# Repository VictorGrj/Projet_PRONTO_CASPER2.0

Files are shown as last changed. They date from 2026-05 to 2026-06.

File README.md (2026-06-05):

# Casper 2.0 – Robot interactif compagnon

Projet PRONTO – IMT Atlantique (S6 2025–2026 – Campus de Brest)

---
## Présentation

La vidéo de présentation du projet est accessible ici : 
https://www.youtube.com/watch?v=T89Vj4Z8cow

---

## Description

Casper 2.0 est un robot compagnon interactif développé dans le cadre du projet PRONTO.

L’objectif est d’améliorer une plateforme robotique existante afin de rendre les interactions plus naturelles et multimodales, en combinant :

- Interaction vocale en langage naturel
- Suivi visuel de l’utilisateur en temps réel
- Gestuelle synchronisée avec la parole
- Dialogue via intelligence artificielle (Google Gemini)

---

## Architecture du système

Le système repose sur une Raspberry Pi comme unité centrale, connectée à plusieurs modules :

- Caméra (vision)
- ReSpeaker Pi HAT (audio)
- API Gemini (IA)
- Synthèse vocale Piper
- Servomoteurs (PCA9685 via I2C)
- Interface graphique (Pygame)

---

## Architecture logicielle

Le projet est entièrement développé en Python avec une architecture multi-thread :

| Module | Rôle |
|---|---|
| `Main.py` | Orchestration globale (machine à états) |
| `AudioProcessing.py` | Capture audio + STT + IA + TTS |
| `CameraTracking.py` | Détection et suivi du visage |
| `Servo.py` | Contrôle des moteurs |
| `Screen.py` | Interface visuelle (expressions) |
| `Speak.py` | Lecture audio |

---

## Pipeline vocal

1. Capture audio via ReSpeaker
2. Transcription via Vosk
3. Traitement de la requête via Google Gemini API
4. Synthèse vocale via Piper TTS
5. Lecture audio synchronisée avec les mouvements

---

## Suivi visuel

- Détection de visage via OpenCV (Haar Cascade)
- Calcul du centre du visage
- Correction du servo moteur de la tête via PCA9685
- Arrêt automatique du tracking pendant la prise de parole

---

## Gestuelle

- Animation des bras synchronisée avec la parole
- Mouvements simplifiés pour réduire la charge CPU
- Optimisation pour Raspberry Pi (limitation des threads et PWM)

---

## Équipe projet

Projet réalisé par une équipe de 5 étudiants :

| Nom |
|-----|
| Greillier Matthieu |
| Lunven Nathan |
| Miannay Benjamin |
| Seillé Gautier |
| Garajeu Victor |

---

## Installation

```bash
git clone https://github.com/VictorGrj/Projet_PRONTO_CASPER2.0.git
cd Projet_PRONTO_CASPER2.0
pip install -r requirements.txt

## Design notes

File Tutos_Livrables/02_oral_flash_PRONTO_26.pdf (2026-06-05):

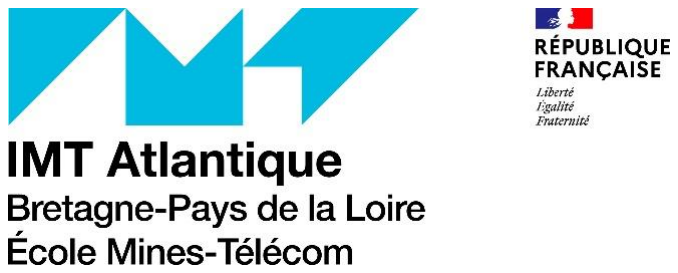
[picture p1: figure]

## PRONTO : Oral Flash Équipe n°2 : Casper 2.0

Garajeu Victor - Greillier Matthieu - Lunven Nathan -

Miannay Benjamin - Seillé Gautier

Encadré par : Lohr Christophe,

Kerdreux Jerôme, Abiven Bernard

## CONTEXTUALISATION

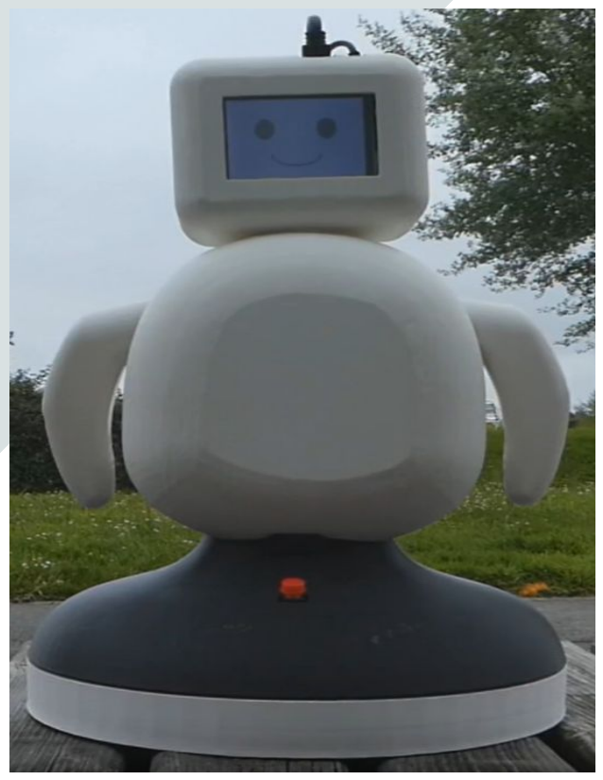
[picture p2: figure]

Casper
PRONTO 2024-2025

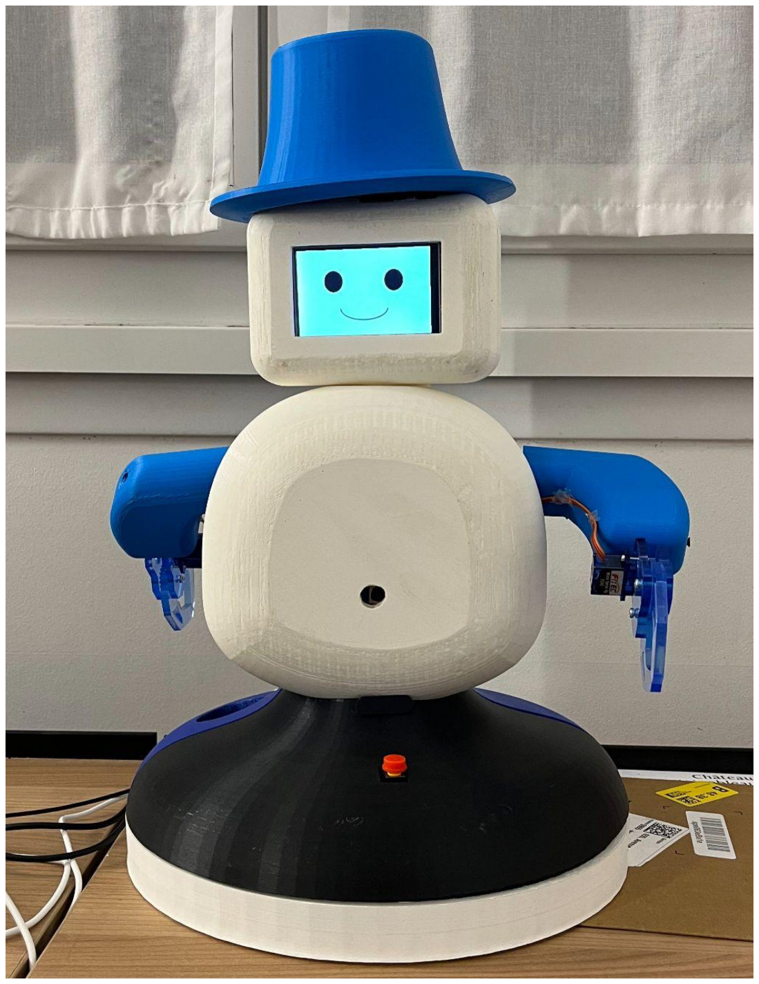
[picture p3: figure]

Casper 2.0
PRONTO 2025-2026

## OBJECTIF

### Comment rendre le robot Casper 2.0 plus naturel et autonome dans ses interactions avec un utilisateur?

## SOMMAIRE

### ❖ Fonctionnalités

### ❖ Méthodologie employée

### ❖ Résultats

### ❖ Perspectives d’amélioration

### ❖ Valorisation du Projet

### ❖ Démonstration

## FONCTIONNALITÉS

1) Interaction vocale
- Réponses générées par
IA
- Retrait du casque audio
- Dialogue vocal naturel
2) Suivi visuel
- Ajout d’une caméra
- Suivi de l’interlocuteur
3) Gestuelle
- Mouvements plus
fluides
- Mouvements en lien
avec la parole
- Nouveaux
servomoteurs
4) Intégration finale
- Robot complet
- Vidéo d’explication
- Tous les fichiers de
conception et de code

## MÉTHODOLOGIE

EMPLOYÉE | Intéraction Vocale

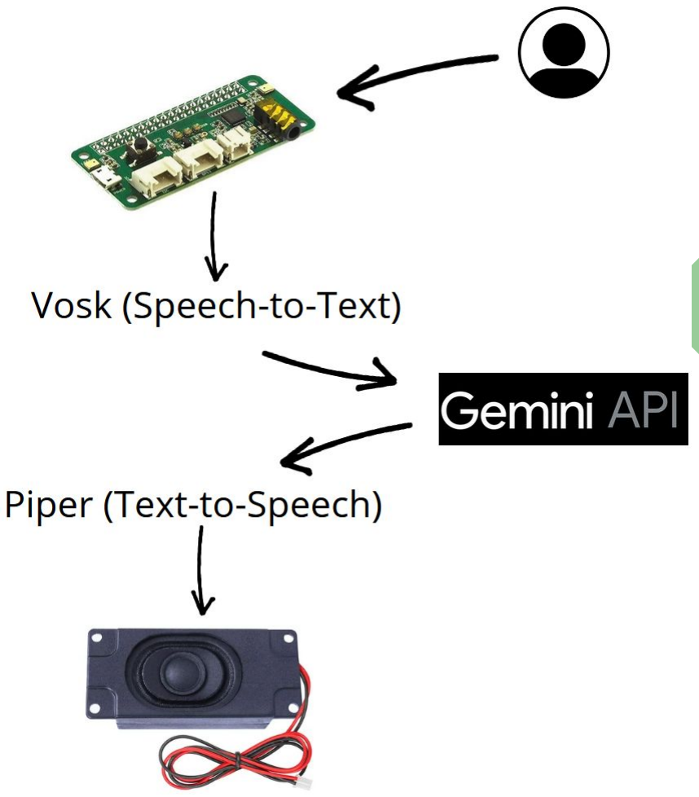
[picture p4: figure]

Objectifs :

- Échange plus fluide
- Génération de réponse par IA
- Ajout du module ReSpeaker

2 Pi HAT

- Test du code

## MÉTHODOLOGIE

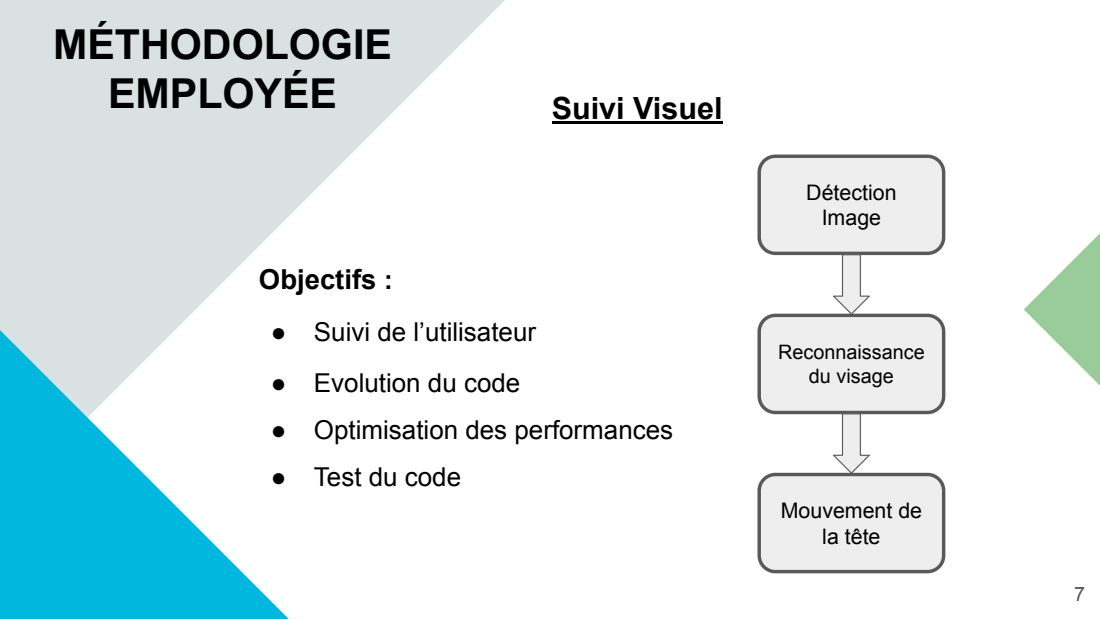
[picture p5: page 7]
EMPLOYÉE; Suivi Visuel; Objectifs :; Détection Image; Mouvement de la tête; Reconnaissance du visage

● Suivi de l’utilisateur

● Evolution du code
● Optimisation des performances

● Test du code

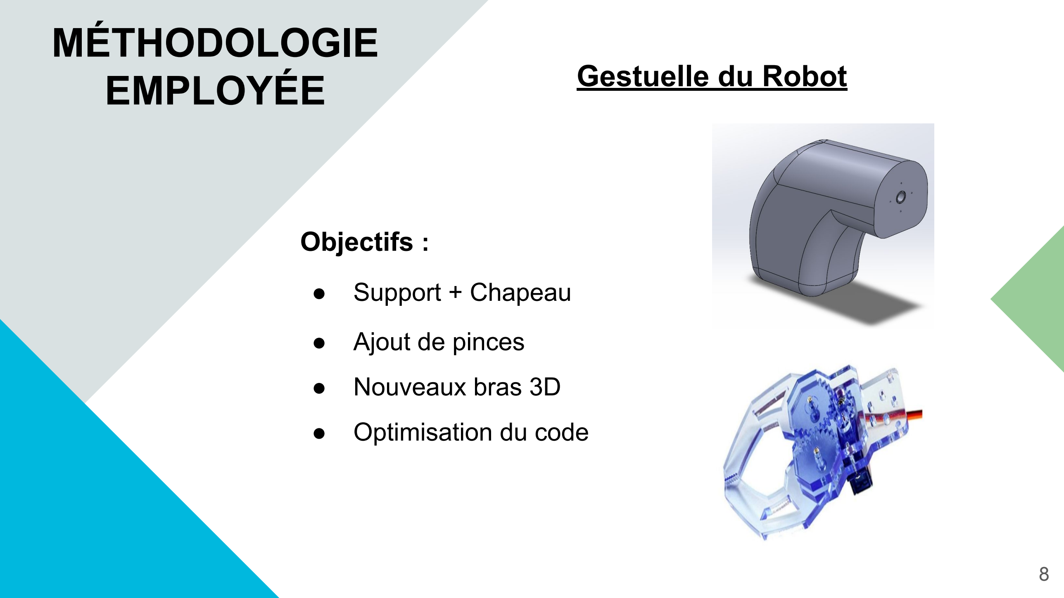
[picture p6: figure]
MÉTHODOLOGIE; EMPLOYÉE; Gestuelle du Robot; Objectifs :; ● Support + Chapeau; ● Ajout de pinces; ● Nouveaux bras 3D; ● Optimisation du code

## RÉSULTATS

1) Interaction vocale
- Réponse générée par IA
→ Réussi
- Dialogue vocal naturel
→ Fonctionnel (30s pour une réponse)
3) Gestuelle
- Mouvement en lien avec la parole → Réussi
- Nouveaux servomoteurs
→ Introduits
2) Suivi visuel
- Ajout d’une caméra
→ Réussi
- Suivi de l’interlocuteur → Réussi mais latence
4) Intégration finale
- Robot complet
→ Réussi
- Vidéo d’explication
→ Présente

Validation :

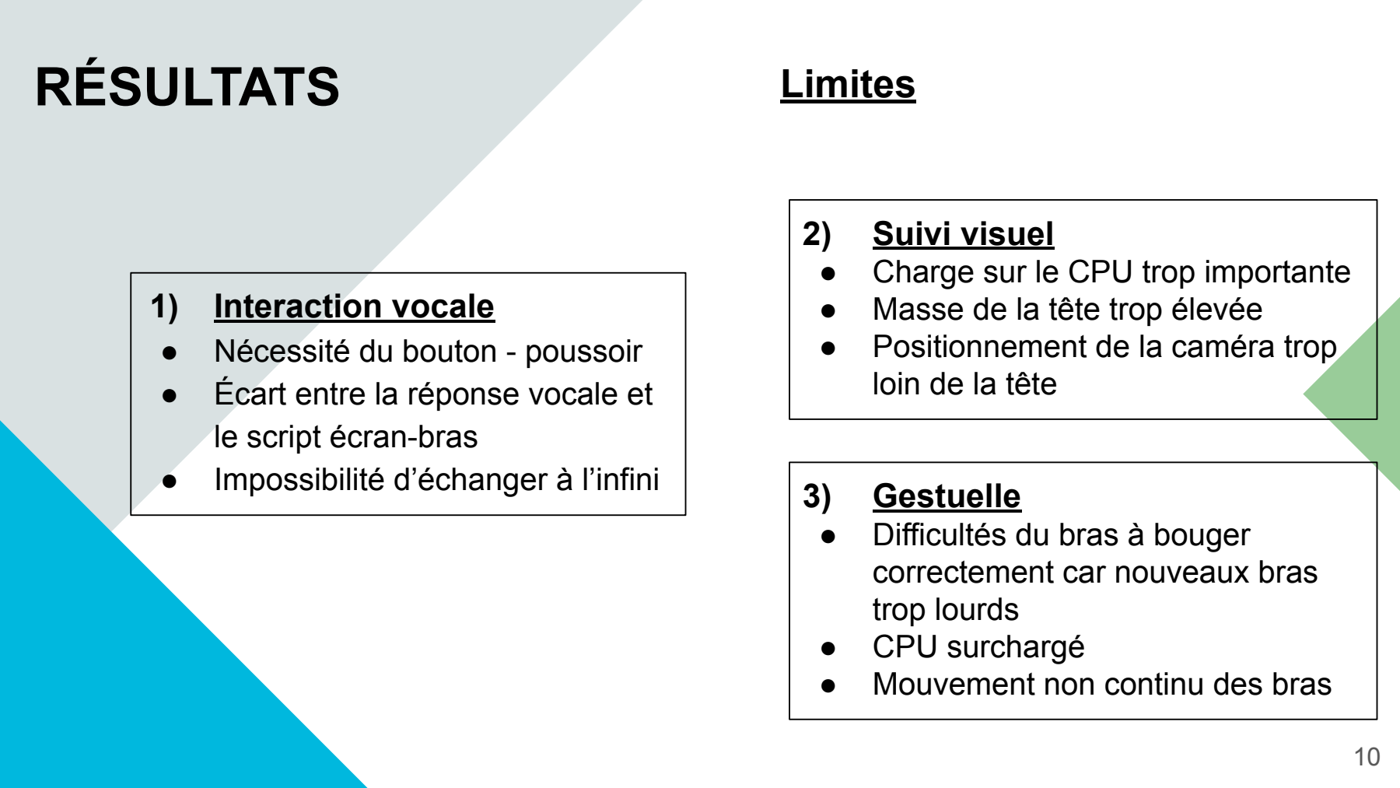
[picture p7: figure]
RÉSULTATS; Limites; 1) Interaction vocale; ● Nécessité du bouton - poussoir ● Écart entre la réponse vocale et; le script écran-bras ● Impossibilité d’échanger à l’infini; 2) Suivi visuel ● Charge sur le CPU trop importante ● Masse de la tête trop élevée ● Positionnement de la caméra trop loin de la tête; 3) Gestuelle ● Difficultés du bras à bouger correctement car nouveaux bras trop lourds ● CPU surchargé ● Mouvement non continu des bras

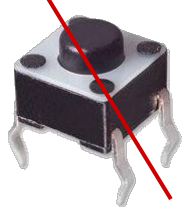
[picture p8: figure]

## PERSPECTIVES D'AMÉLIORATION

Objectifs:

- Remplacement du bouton par un mot-clé vocal
- Historique de conversation avec Gemini
- Localisation de la voix grâce aux deux microphones du ReSpeaker
- Gestuelle plus fluide

## VALORISATION DU PROJET

Méthode CAR

Contexte :

Modernisation d'un robot compagnon existant

Actions :

- Intégration de la vision à l’aide de la caméra
- Remplacement de wikipedia par gemini
- Conception et impression 3D de nouvelles pièces mécaniques

Résultats :

Réalisation d'un prototype capable de suivre un utilisateur et d'interagir vocalement de manière fluide

## Conclusion

Objectif atteint

- Interaction vocale avec intelligence artificielle
- Suivi visuel de l'utilisateur
- Gestuelle synchronisée avec la parole
- Intégration complète sur Raspberry Pi

Ce que nous retenons

- Développement d'un système robotique complet
- Intégration de plusieurs technologies (vision, audio, IA, mécanique)
- Travail d'équipe et gestion d'un projet d'ingénierie

# Avez-vous des questions ?

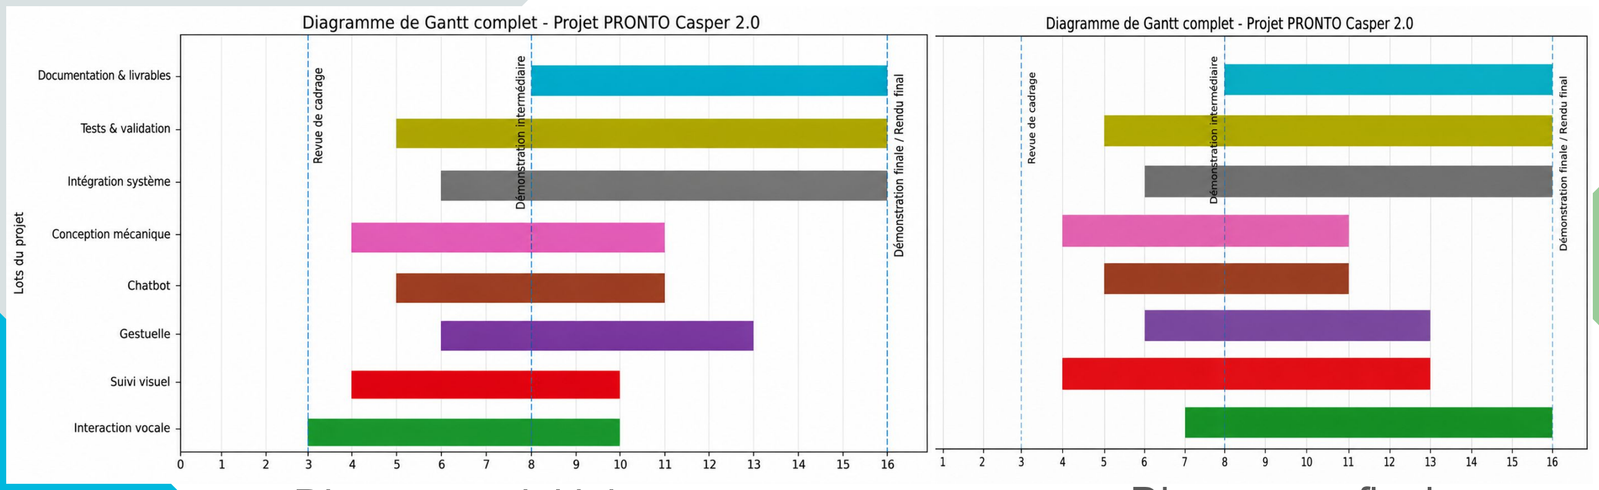
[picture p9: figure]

Diagramme initial | Diagramme final

Planification temporelle

## MÉTHODOLOGIE EMPLOYÉE

## VALORISATION DU PROJET

- Casper initial peu esthétique, avec des interactions limitées
- Modification des codes et ajout de périphérique afin de fluidifier les interactions
- Impression 3D afin de résoudre les problèmes d’esthétisme
- Obtention d’un robot plus esthétique pouvant avoir des interactions plus naturelles
- Gain en compétences
techniques (code et CAO)
- Première expérience
projet entreprise
- Gain en compétences de
gestion de projet de
groupes (prise de
décision collective,
gestion des conflits, ...)

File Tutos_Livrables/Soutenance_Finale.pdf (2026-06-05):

# PRONTO : Présentation finale Équipe n°2 : Casper 2.0

Garajeu Victor - Greillier Matthieu - Lunven Nathan -

Miannay Benjamin - Seillé Gautier

Encadré par : Lohr Christophe,

Kerdreux Jerôme, Abiven Bernard

## PROBLÉMATIQUE

ET

## OBJECTIF

## Comment implanter un chatbot dans le robot Casper, tout en y implémentant un suivi visuel et des mouvements en simultané ?

## SOMMAIRE

### ❖ Cahier des charges

### ❖ Conception du système

### ❖ Développement logiciel

### ❖ Intégration et validation

### ❖ Organisation et équipe

### ❖ Conclusion

## CAHIER DES CHARGES

1) Interaction vocale
- Ajout du Chatbot
- Retrait du casque
- Interaction plus fluide
2) Suivi visuel
- Ajout d’une caméra
- Suivi de l’interlocuteur
3) Gestuelle
- Mouvements plus
fluides
- Mouvements en lien
avec la parole
- Nouveaux
servomoteurs
4) Intégration finale
- Robot complet
- Vidéo d’explication
- Tous les fichiers de
conception et de code

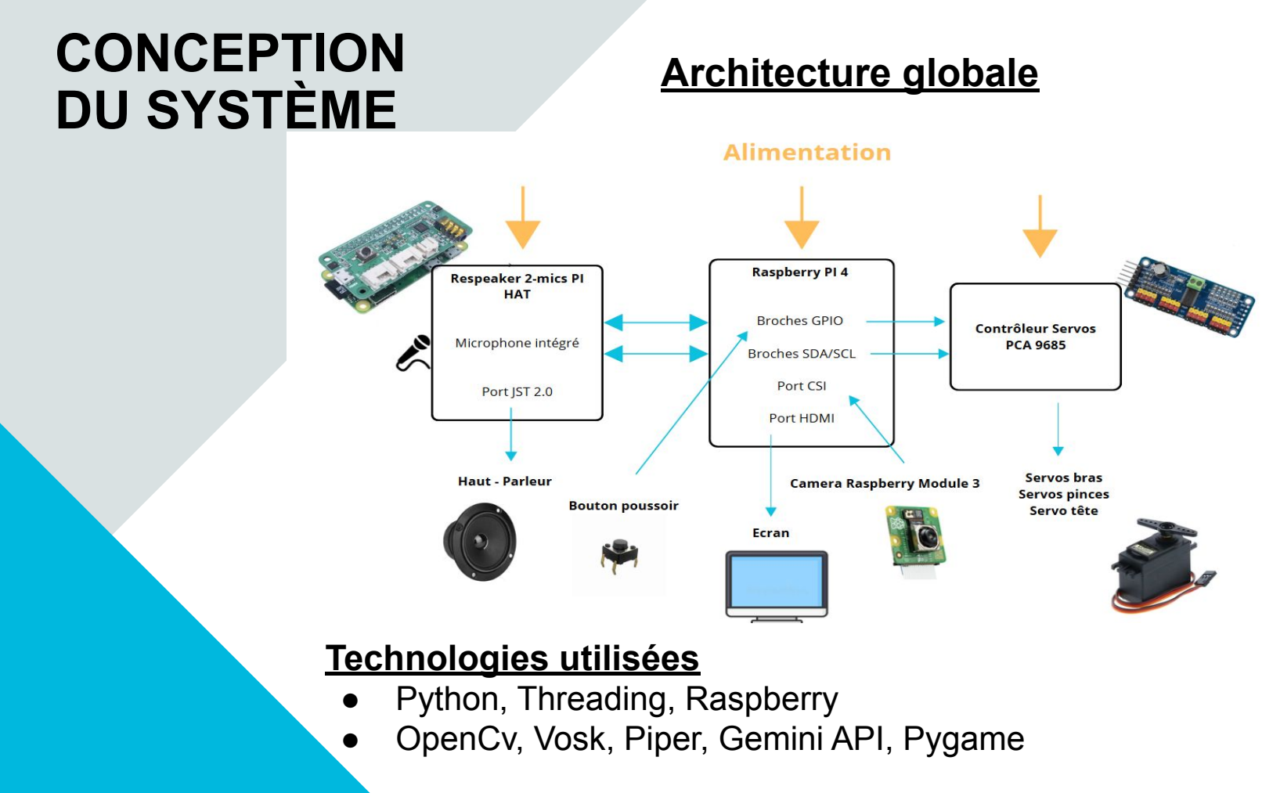
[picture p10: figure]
CONCEPTION DU SYSTÈME; Architecture globale; Technologies utilisées ● Python, Threading, Raspberry

- OpenCv, Vosk, Piper, Gemini API, Pygame

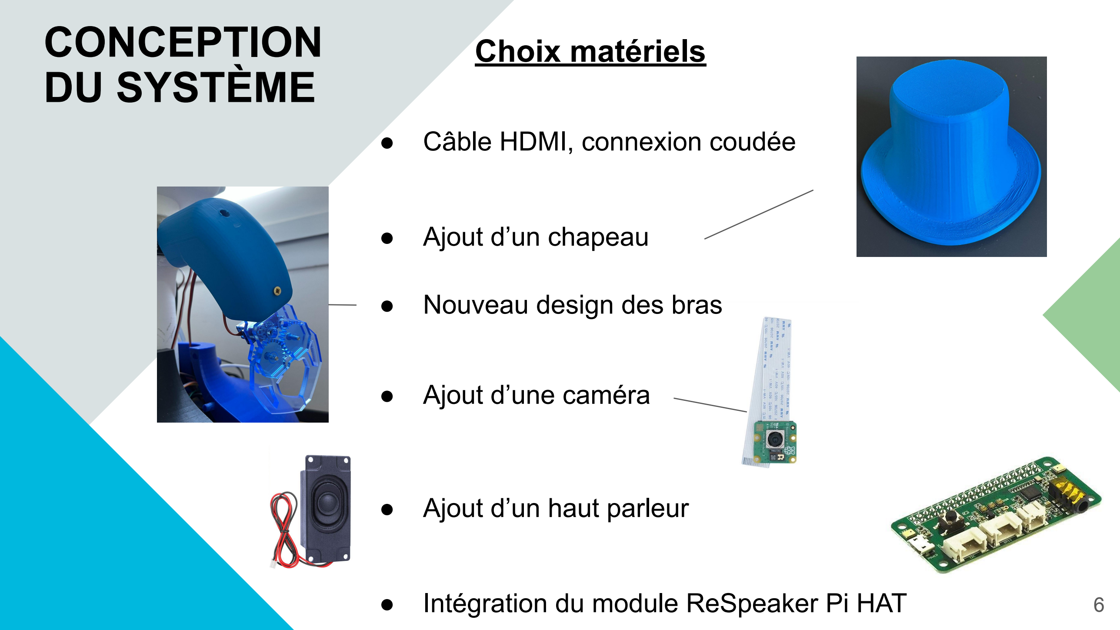
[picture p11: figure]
● Ajout d’un haut parleur; CONCEPTION DU SYSTÈME; Choix matériels; ● Câble HDMI, connexion coudée; ● Ajout d’un chapeau; ● Nouveau design des bras; ● Ajout d’une caméra

- Intégration du module ReSpeaker Pi HAT

### Interaction vocale

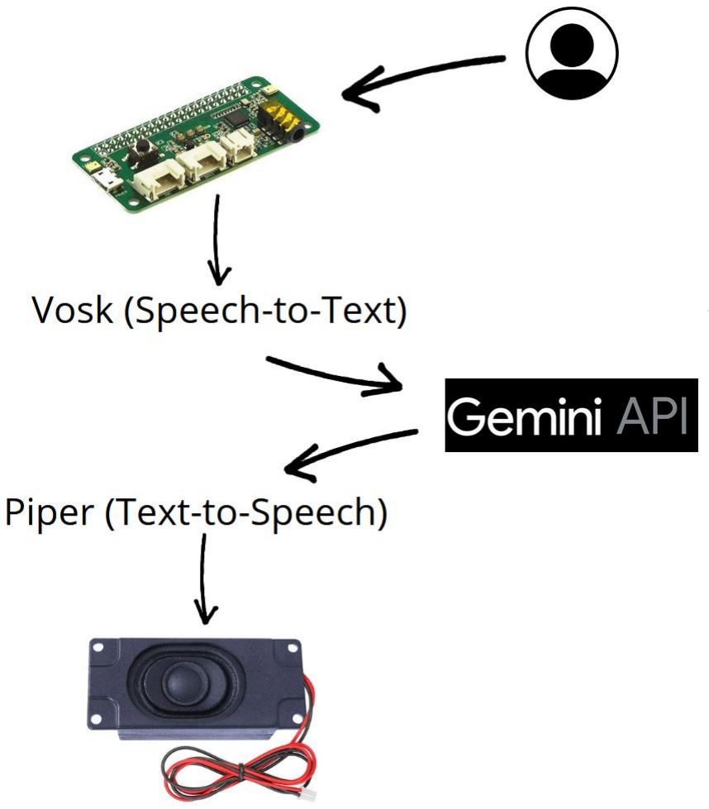
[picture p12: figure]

Objectifs :

- Échange plus fluide
- Utilisation d’une API IA (Gemini)
- Ajout du module ReSpeaker 2 Pi HAT
- Test du code

## DÉVELOPPEMENT DU SYSTÈME

## DÉVELOPPEMENT

DU SYSTÈME | Fonctionnement

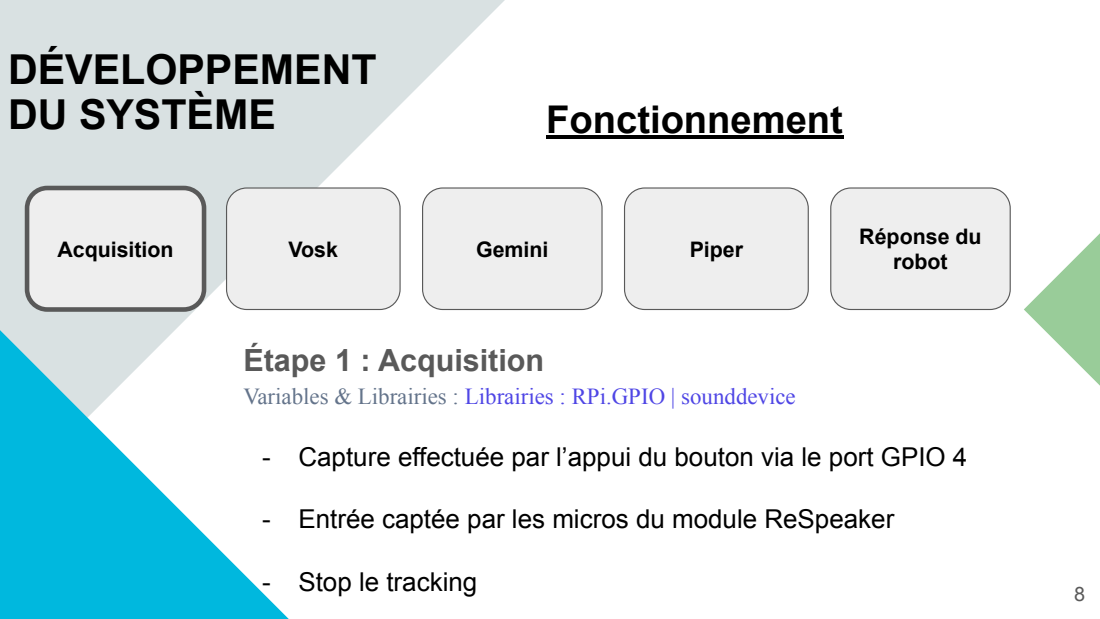
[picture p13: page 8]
Acquisition; Vosk; Gemini; Piper; Réponse du; robot; Étape 1 : Acquisition

Variables & Librairies : Librairies : RPi.GPIO | sounddevice

- Capture effectuée par l’appui du bouton via le port GPIO 4

- Entrée captée par les micros du module ReSpeaker

- Stop le tracking

## Fonctionnement

## DÉVELOPPEMENT

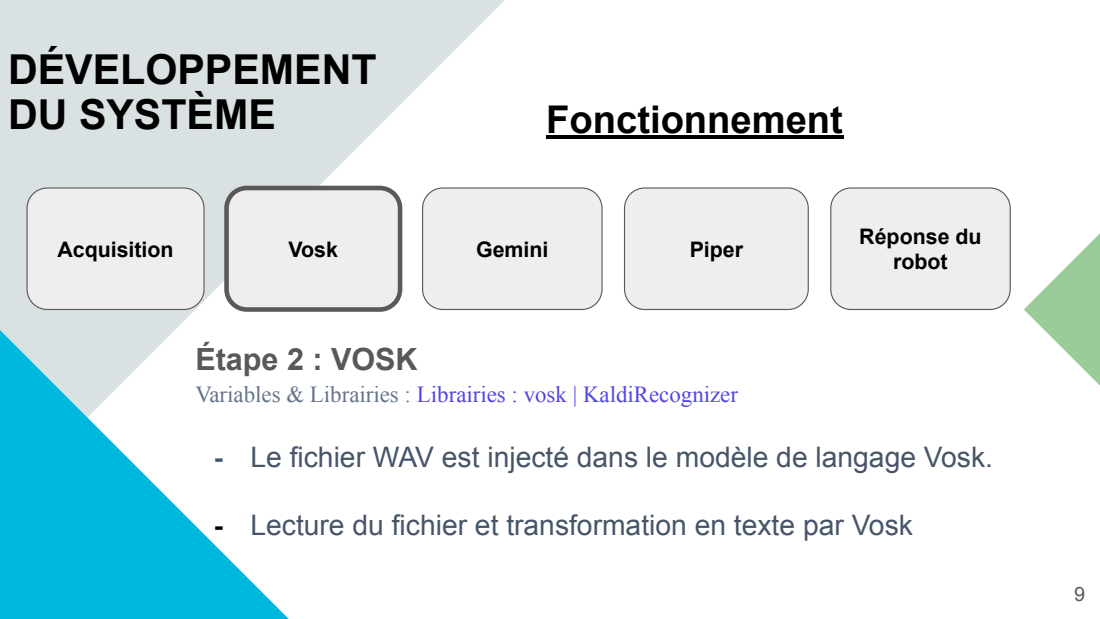
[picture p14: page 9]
Acquisition; Vosk; Gemini; Piper; Réponse du; robot; Étape 2 : VOSK; DU SYSTÈME

Variables & Librairies : Librairies : vosk | KaldiRecognizer

- Le fichier WAV est injecté dans le modèle de langage Vosk.

- Lecture du fichier et transformation en texte par Vosk

## Fonctionnement

## DÉVELOPPEMENT

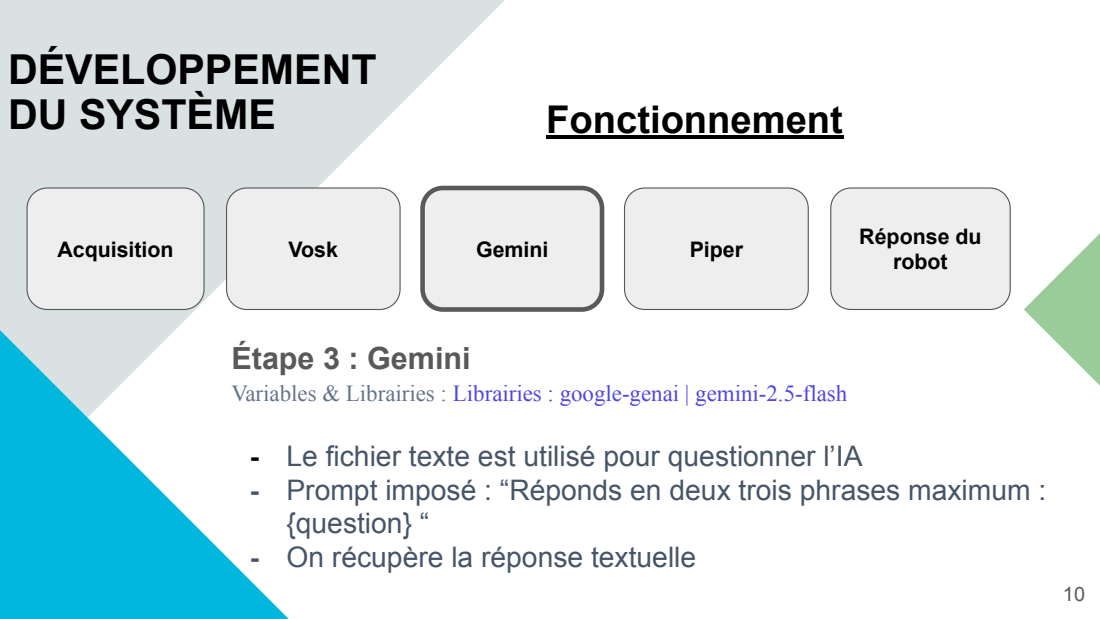
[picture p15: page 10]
Acquisition; Vosk; Gemini; Piper; Réponse du; robot; Étape 3 : Gemini; DU SYSTÈME

Variables & Librairies : Librairies : google-genai | gemini-2.5-flash

- Le fichier texte est utilisé pour questionner l’IA
- Prompt imposé : “Réponds en deux trois phrases maximum :
{question} “
- On récupère la réponse textuelle

## Fonctionnement

## DÉVELOPPEMENT

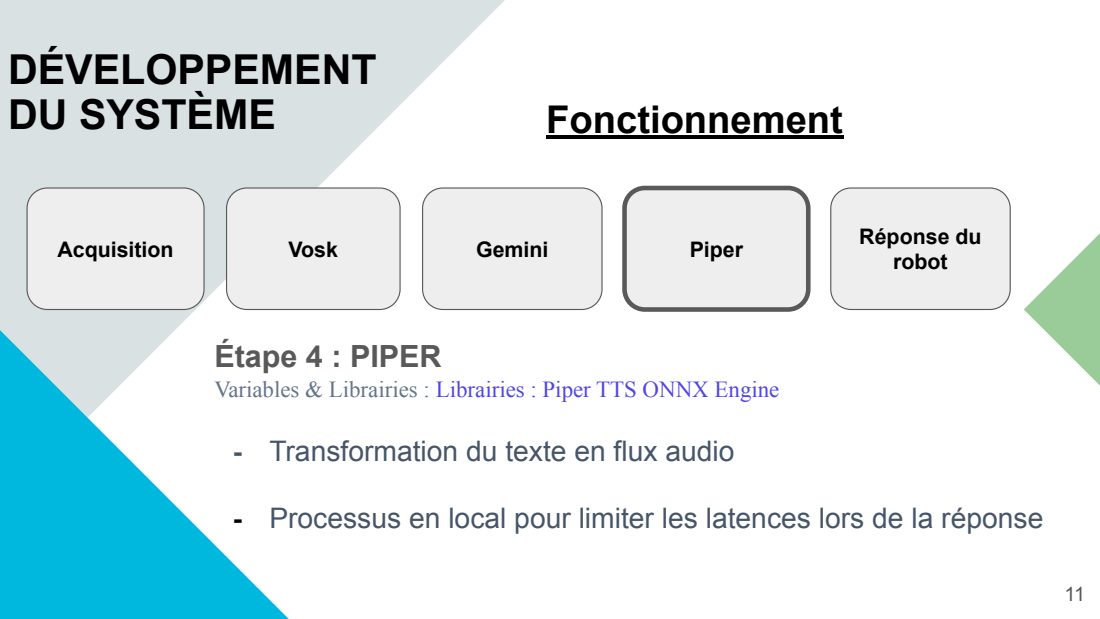
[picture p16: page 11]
Acquisition; Vosk; Gemini; Piper; Réponse du; robot; Étape 4 : PIPER; DU SYSTÈME

Variables & Librairies : Librairies : Piper TTS ONNX Engine

- Transformation du texte en flux audio

- Processus en local pour limiter les latences lors de la réponse

## Fonctionnement

## DÉVELOPPEMENT

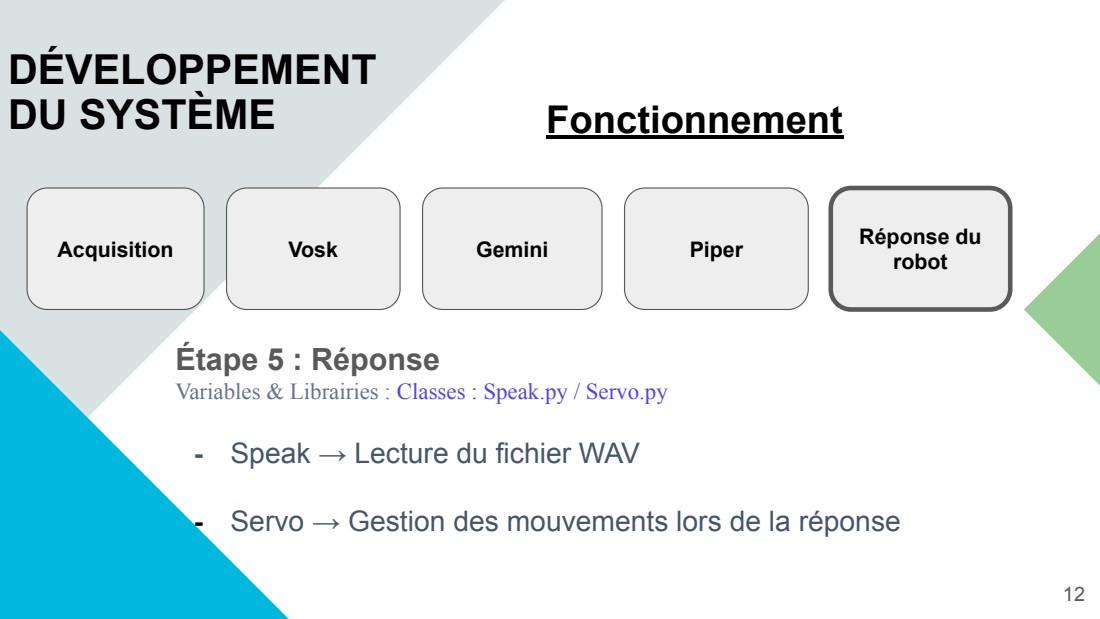
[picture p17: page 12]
Acquisition; Vosk; Gemini; Piper; Réponse du; robot; Étape 5 : Réponse; DU SYSTÈME

Variables & Librairies : Classes : Speak.py / Servo.py

- Speak → Lecture du fichier WAV

- Servo → Gestion des mouvements lors de la réponse

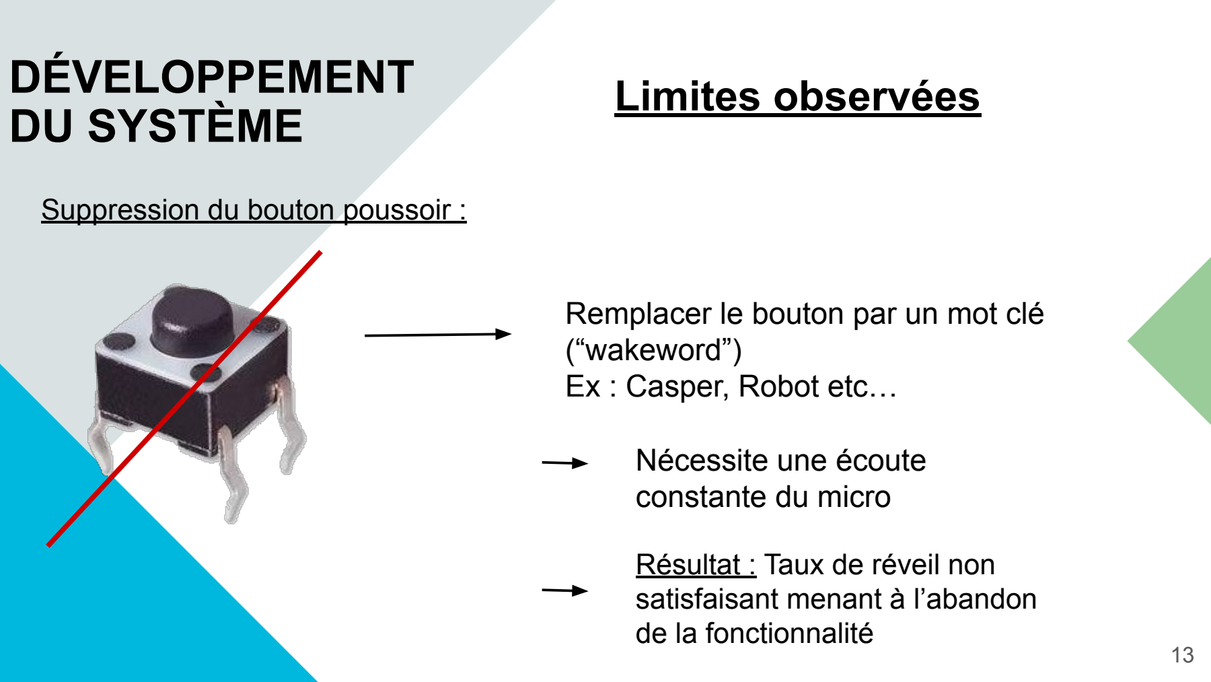
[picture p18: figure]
Limites observées; Suppression du bouton poussoir :; Remplacer le bouton par un mot clé (“wakeword”) Ex : Casper, Robot etc…; Nécessite une écoute constante du micro; Résultat : Taux de réveil non satisfaisant menant à l’abandon de la fonctionnalité; DÉVELOPPEMENT DU SYSTÈME

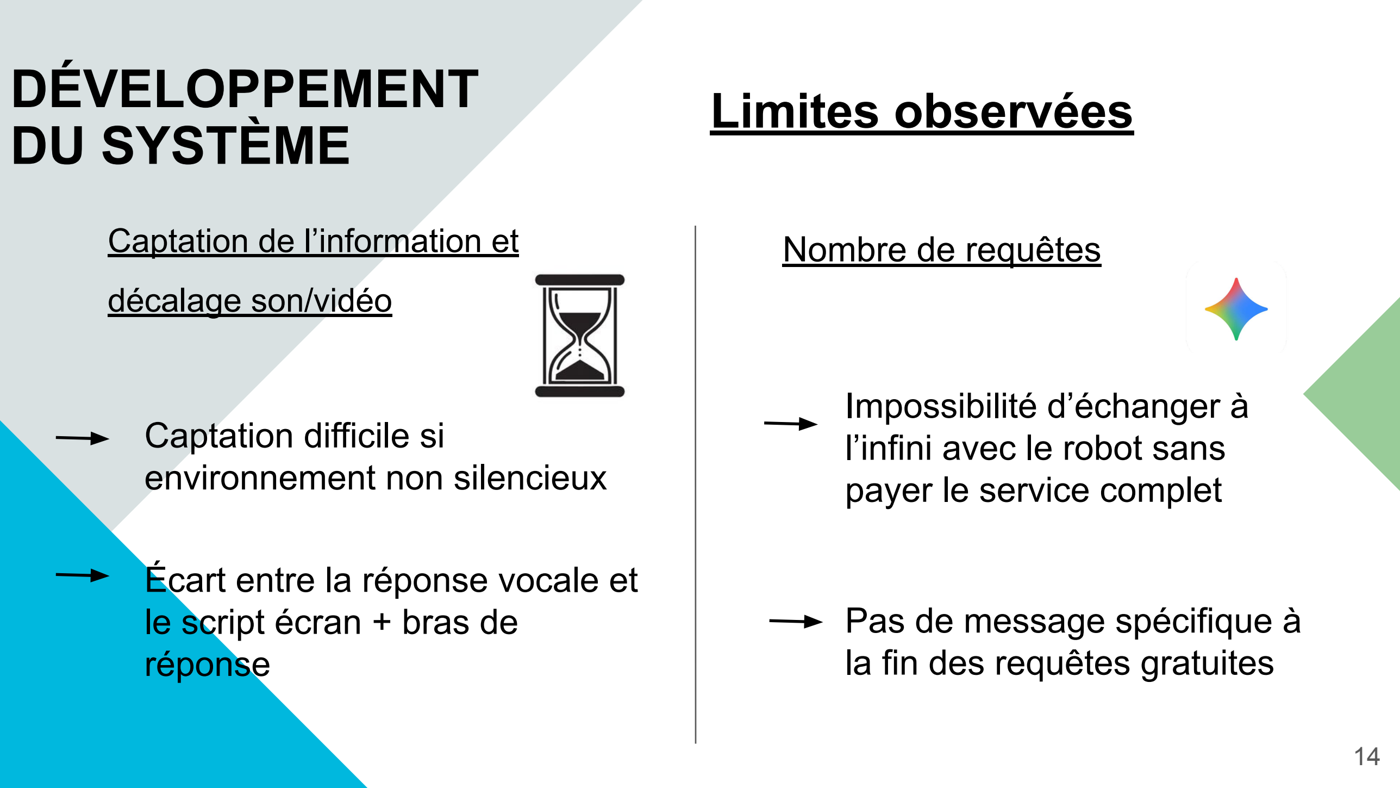
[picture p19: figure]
Limites observées; Captation de l’information et; décalage son/vidéo; Captation difficile si environnement non silencieux; Écart entre la réponse vocale et le script écran + bras de réponse; Nombre de requêtes; Impossibilité d’échanger à l’infini avec le robot sans payer le service complet; Pas de message spécifique à la fin des requêtes gratuites; DÉVELOPPEMENT DU SYSTÈME

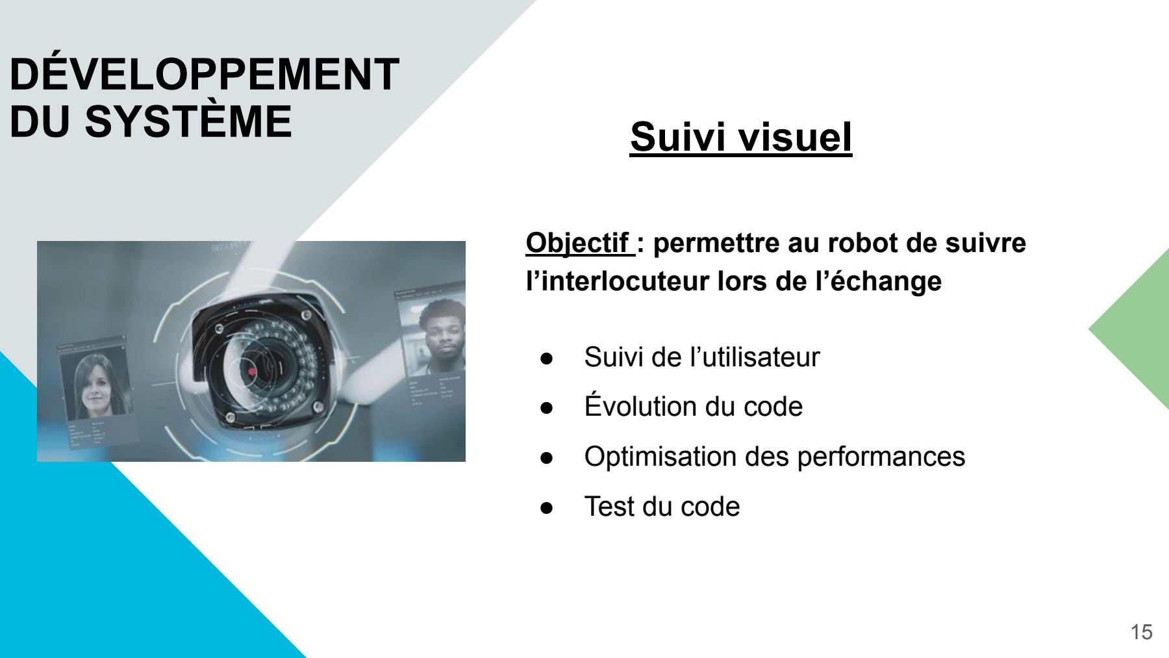
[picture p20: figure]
Suivi visuel; Objectif : permettre au robot de suivre l’interlocuteur lors de l’échange; ● Suivi de l’utilisateur; ● Évolution du code; ● Optimisation des performances; ● Test du code; DÉVELOPPEMENT DU SYSTÈME

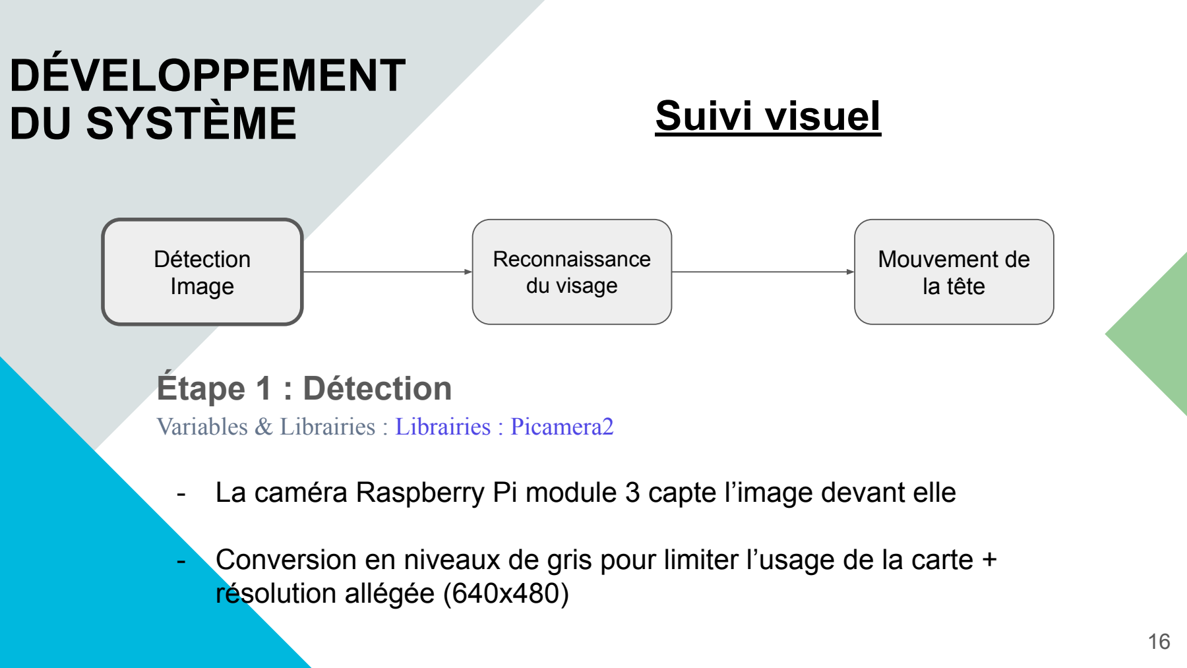
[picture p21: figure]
Suivi visuel; Détection Image; Reconnaissance du visage; Mouvement de la tête; Étape 1 : Détection; résolution allégée (640x480); DÉVELOPPEMENT DU SYSTÈME

Variables & Librairies : Librairies : Picamera2

- La caméra Raspberry Pi module 3 capte l’image devant elle
- Conversion en niveaux de gris pour limiter l’usage de la carte +

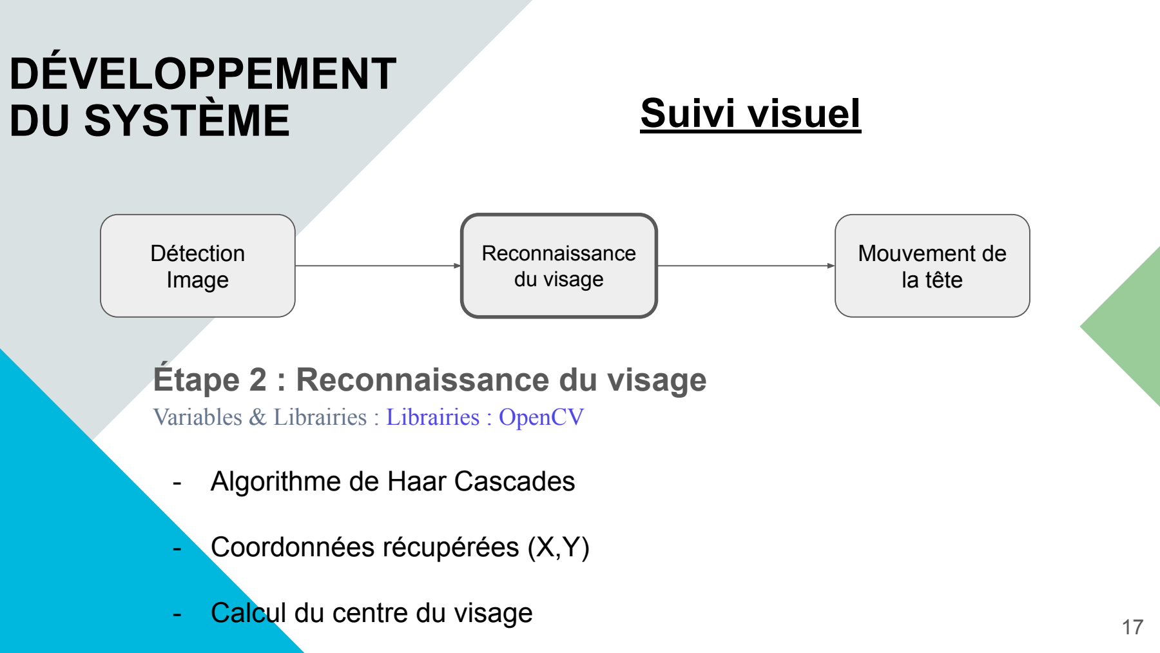
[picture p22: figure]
Suivi visuel; Détection Image; Reconnaissance du visage; Mouvement de la tête; Étape 2 : Reconnaissance du visage; - Algorithme de Haar Cascades; - Coordonnées récupérées (X,Y); - Calcul du centre du visage; DÉVELOPPEMENT DU SYSTÈME

Variables & Librairies : Librairies : OpenCV

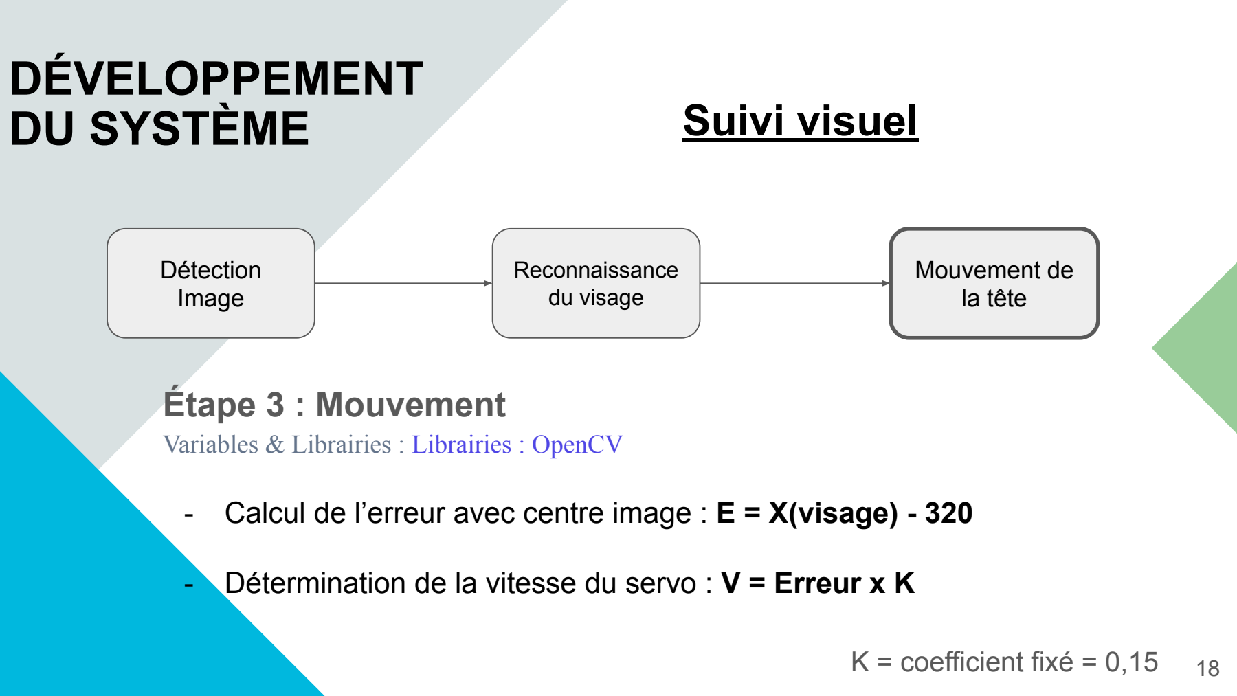
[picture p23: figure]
Suivi visuel; Détection Image; Reconnaissance du visage; Mouvement de la tête; Étape 3 : Mouvement; K = coefficient fixé = 0,15; DÉVELOPPEMENT DU SYSTÈME

Variables & Librairies : Librairies : OpenCV

- Calcul de l’erreur avec centre image : E = X(visage) - 320
- Détermination de la vitesse du servo : V = Erreur x K

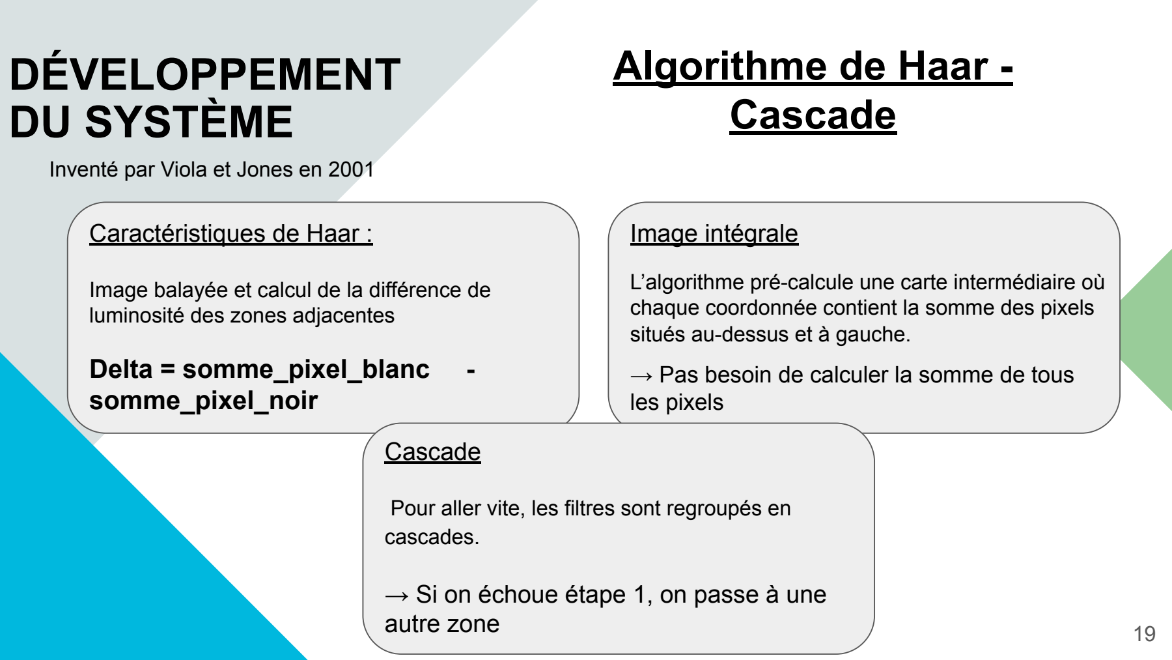
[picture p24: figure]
DÉVELOPPEMENT DU SYSTÈME; Algorithme de Haar - Cascade; Inventé par Viola et Jones en 2001; Caractéristiques de Haar :; luminosité des zones adjacentes; Delta = somme_pixel_blanc; somme_pixel_noir; Image intégrale; situés au-dessus et à gauche.; les pixels; Cascade; cascades.; → Si on échoue étape 1, on passe à une autre zone

Image balayée et calcul de la différence de

L’algorithme pré-calcule une carte intermédiaire où chaque coordonnée contient la somme des pixels

→ Pas besoin de calculer la somme de tous

Pour aller vite, les filtres sont regroupés en

## Limites de la feature

- Charge sur le CPU :

→ Malgré la coupure du script pendant la discussion, le tracking reste

vorace pour la Raspberry

- Longueur de la nappe :

→ Positionnement de la caméra loin de la tête

- Masse de la tête :

→ Mouvements saccadés lors du tracking

## DÉVELOPPEMENT DU SYSTÈME

## DU SYSTÈME


Diagramme initial | Diagramme final
DÉVELOPPEMENT | Planification temporelle

Gestuelle du robot; Objectif : Mouvements fluides adaptés; Optimisation du code :; Esthétisme :; → Méthode simple de mouvement lors de la réponse; → Limite l’usage du CPU; → Pinces en mouvement en même temps que les bras; DÉVELOPPEMENT DU SYSTÈME

### Limites

Ressources CPU :

100% des capacités du CPU sont utilisées pour la génération de la réponse

→ Mouvements des bras en
continu impossible sans surcharger la carte

Masse du nouveau bras

→ Masse des pinces à ajouter

→ Bras de levier plus important

## DÉVELOPPEMENT DU SYSTÈME

INTÉGRATION ET; VALIDATION; Ajouts sur la tête; → Exige de creuser la tête

Support Écran | Repose - Chapeau | Coude HDMI

## INTÉGRATION ET

## VALIDATION


### Ajouts sur les bras

Nouveaux bras | Pinces | Fixation des fils

Insertion dans
l'encoche du bras

## INTÉGRATION ET

## VALIDATION


Autres ajouts

Trou pour la caméra

ReSpeaker + extension GPIO

Servos
Bouton

Validation :

1) Interaction vocale
- Ajout Chatbot
→ Réussi
- Interaction plus fluide
→ Temps d’attente similaire
2) Suivi visuel
- Ajout d’une caméra
→ Réussi
- Suivi de l’interlocuteur → Réussi mais latence
3) Gestuelle
- Mouvement en lien avec la parole → Réussi
- Nouveaux servomoteurs
→ Introduits
4) Intégration finale
- Robot complet
→ Réussi
- Vidéo d’explication
→ Présente

## INTÉGRATION ET

## VALIDATION

ORGANISATION D’ÉQUIPE; Difficultés ● Travail cloisonné ● Communication limitée ● Retards; Solutions ● Points hebdomadaires ● Validation croisée ● Répartition plus souple; Résultats ● Meilleure cohésion ● Travail plus efficace; Climat au sein de l’équipe

## DÉMONSTRATION


## CONCLUSION


- Respect partiel du cahier des charges
- Réorganisation de l’équipe
- Amélioration du climat
- Efficacité augmentée

# Avez-vous des

# questions?

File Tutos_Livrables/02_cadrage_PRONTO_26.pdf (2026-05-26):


IMT Atlantique

Projet PRONTO – S6 2025-2026

Campus de Brest

Auteur 1 : Garajeu Victor

Auteur 2 : Greillier Matthieu

Auteur 3 : Lunven Nathan

Auteur 4 : Miannay Benjamin

Auteur 5 : Seillé Gautier

Encadré par : Lohr Christophe, Kerdreux Jerôme, Abiven Bernard

# PRONTO, S6 2025/2026

# Equipe n°2: Casper 2.0

# Document de cadrage

Version : 1.0

Date : 11 février 2026

## Table des matières

### INTRODUCTION :

L’Interaction Humain-Robot (Human-Robot Interaction, HRI) constitue un domaine de recherche majeur visant à améliorer l’acceptabilité, la compréhension et l’engagement des utilisateurs face aux systèmes robotiques.
Dans ce contexte, l’équipe de recherche RAMBO d’IMT Atlantique dispose d’une plate-forme robotique modulaire existante, nommée Wikibot, capable d’interagir vocalement avec un utilisateur en fournissant des définitions issues de Wikipédia.
Bien que fonctionnelle, cette première version présente plusieurs limitations, notamment une interaction essentiellement statique, l’absence de perception visuelle de l’interlocuteur et une interface audio peu adaptée à un usage naturel.
Le projet PRONTO « Robots compagnon : Casper 2.0 » s’inscrit dans la continuité de ce travail et vise à enrichir les capacités du robot afin de proposer des interactions plus naturelles, à la fois vocales et non verbales.

Le présent document constitue le document de cadrage du projet. Il présente l’état initial du projet à l’issue de la phase de cadrage, en abordant les aspects scientifiques, techniques et organisationnels, et servira de référence pour la préparation des revues de projet et d’équipe.

## Présentation du projet :

Le projet s’inscrit dans une démarche expérimentale en Interaction Humain-Robot (HRI), visant à améliorer la qualité et la naturalité des échanges entre un humain et un système robotique.

Finalité :
La finalité du projet est de contribuer à l’étude de l’acceptabilité des robots compagnons en proposant une plate-forme robotique capable de présence physique et d’interaction naturelle avec un utilisateur humain.

Mission :

La mission du système Casper 2.0 est d’étendre les capacités du robot existant en intégrant une interaction conversationnelle basée sur un chatbot en ligne. Un chatbot est un agent conversationnel logiciel capable de dialoguer automatiquement avec un utilisateur en langage naturel, généralement via une interface textuelle ou vocale, en s’appuyant sur des modèles de traitement automatique du langage. De plus le robot doit aussi intégrer un suivi visuel de l’interlocuteur et une gestuelle simple et fluide, afin de renforcer l’impression de présence et d’engagement durant l’échange.

Objectif :
Pour remplir cette mission, le projet vise notamment à :
- Permettre une interaction vocale compréhensible jusqu’à une distance de 3 mètres ;

- Assurer un suivi visuel de l’interlocuteur en temps quasi réel ;
- Synchroniser la gestuelle du robot avec la parole lors d’une interaction ;
- Livrer un prototype fonctionnel démontrable en environnement intérieur.

Contexte et problématique :
Le robot précédemment développé, Wikibot, se limitait à la restitution de définitions issues de Wikipédia et ne permettait pas une interaction conversationnelle riche. De plus, l’absence de perception visuelle et l’utilisation d’une interface audio contraignante limitent fortement la naturalité des échanges.
La problématique du projet consiste donc à concevoir une évolution du robot existant permettant une interaction plus naturelle, tout en respectant les contraintes de modularité, de calcul embarqué et d’environnement d’utilisation propres à la plate-forme existante.

## Cahiers des charges fonctionnel :

Le cahier des charges fonctionnel du projet Casper 2.0 définit les fonctions principales et contraintes nécessaires à la réalisation d’un robot compagnon capable d’interaction naturelle avec un utilisateur. Les fonctions principales concernent :

- L’interaction vocale avec l’utilisateur (captation et restitution du son)
- L’interfaçage avec une solution de chatbot en ligne
- Le suivi visuel de l’interlocuteur par mouvement de la tête
- L’animation gestuelle simple du robot lors des échanges

Les contraintes identifiées portent notamment sur :

- L’alimentation électrique du système
- L’intégration matérielle des composants (caméra, audio)
- La modularité et la maintenabilité du robot

La validation du besoin reposera sur des démonstrations expérimentales du prototype en conditions d’usage représentatives.

## Plan de Travail :

Etapes :
Le projet Casper 2.0 sera mené en effectuant des tâches en parallèles, combinant le développement logiciel, l’intégration matérielle et la conception mécanique.

Les étapes majeures du projet sont les suivantes :
- Prise en main du robot existant (Wikibot) et analyse de l’architecture matérielle et logicielle
- Etude et intégration d’un système de suivi visuel de l’interlocuteur à l’aide d’une caméra embarquée

- Développement et amélioration des algorithmes de mouvement afin d’obtenir une gestuelle fluide et naturelle
- Interfaçage avec une solution de chatbot en ligne pour permettre une interaction conversationnelle enrichie
- Conception et redesign de certaines pièces mécaniques afin d’intégrer les nouveaux composants tout en conservant la modularité du robot
- Intégration d’un système audio adapté (microphone et haut-parleur)
- Tests fonctionnels et démonstration du prototype final

Bibliographie :

Détail du projet précédent, base de notre compagnon à améliorer :

L. BONDUELLE, C. FELTIN, F. THOLLOT, A. MARION. « WIKIBOT - PROJET PRONTO »
HTTPS://GITHUB.COM/ASTRIDMARION/PROJET-PRONTO

Code permettant un suivi par reconnaissance faciale via une caméra :

W. COGLEY. « CAMERA-EYE FOLLOWER BOT » https://www.notion.so/nilheim-mechatronics/Camera-Eye-Follower-Bot-25524779b64d80969680f8a0c32fa70 (https://www.notion.so/nilheim-mechatronics/Camera-Eye-Follower-Bot-25524779b64d80969680f8a0c32fa70)

## Organisation de l’équipe :

Présentation :

L’équipe projet est composé de cinq étudiants aux compétences complémentaires en électronique, mécatronique, informatique, et rédaction technique.

- GARAJEU Victor, Compétences : Programmation, électronique, CAO ; Rôle technique principal : Responsable code et mécatronique
- GREILLIER Matthieu, Compétences : Electronique, mécatronique, bureautique ; Rôle technique principal : Responsable mécatronique
- SEILLE Gautier, Compétences : Electronique, mécatronique, CAO ; Rôle technique principale : Responsable CAO et conception mécanique
- LUNVEN Nathan, Compétences : Programmation, électronique ; Rôle technique principal : Responsable développement logiceil
- MIANNAY Benhamin, Compétences : Rédaction technique, structuration de documents ; Rôle technique principale : Responsable rédaction et livrable documentaires
•

Les rôles organisationnels (chef de projet, secrétaire, responsable bien-être) sont tournants afin de favoriser l’implication de tous les membres dans la gestion du projet. La répartition hebdomadaire de ces rôles est détaillée dans un tableau de suivi.

Périodes du 10/02 au 07/04

Rôle | 10/02-24/02 | 25/02-10/03 | 11/03-24/03 | 25/03-07/04
Manager | Gautier | Gautier | Benjamin | Benjamin
Médiateur | Victor | Matthieu | Nathan | Matthieu
Secrétaire général | Nathan | Victor | Gautier | Nathan

Périodes du 08/04 au 02/06

Rôle | 08/04-21/04 | 22/04-05/05 | 06/05-19/05 | 20/05-02/06
Manager | Victor | Victor | Matthieu | Matthieu
Médiateur | Nathan | Gautier | Gautier | Benjamin
Secrétaire général | Matthieu | Nathan | Victor | Gautier

Les moyens de communication que nous allons utiliser au cours de ce projet sont les suivants.

Communication interne :

- WhatsApp : communication quotidienne, organisation rapide et coordination de l’équipe
- Google Drive : partage et rédaction collaborative des documents
- GitLab : gestion du code source et versionnement des développements logiciels
- Overleaf : rédaction collaborative des rapports en LaTeX lors des phases de rendu
- Doc : rédaction collaborative des rapports sous forma Word lors des phases de rendu

Communication externe :

Messagerie Zimbra : échanges formels avec les encadrants du projet (hebdomadaire ou selon besoin).

WBS :

La structure de découpage du projet (WBS) est présentée ci-dessous. Elle décrit les lots principaux nécessaires à la réalisation du projet Casper 2.0, depuis la prise en main du robot existant jusqu’à la validation et la documentation du prototype final.


Les lots principaux présentés dans le WBS regroupent plusieurs sous-tâches techniques nécessaires à la réalisation complète du projet.
Le lot Analyse et prise en main comprend l’étude de l’architecture matérielle et logicielle du robot existant (Wikibot), la compréhension des flux de communication internes ainsi que l’évaluation des performances actuelles du système.
Le lot Développement logiciel intègre le développement des modules d’interaction vocale (capture et restitution audio), l’interfaçage avec une solution de chatbot en ligne, la mise en place d’un système de suivi visuel de l’interlocuteur via une caméra embarquée ainsi que l’amélioration des algorithmes de mouvement pour synchroniser la gestuelle avec la parole.
Le lot Conception mécanique comprend l’adaptation et le redesign de certaines pièces du robot afin d’intégrer les nouveaux composants (caméra, système audio), la modélisation CAO et la préparation des fichiers destinés à la fabrication.
Le lot Intégration et validation regroupe l’assemblage progressif des différents modules développés, la réalisation de tests fonctionnels intermédiaires, l’optimisation des performances et la validation expérimentale en conditions représentatives d’usage.
Enfin, le lot Documentation et livrables inclut la rédaction des documents scientifiques et techniques, la production du dossier de conception, du tutoriel Do-It-Yourself ainsi que la préparation de la démonstration finale et des supports de communication.

Planification temporelle du projet : Le projet Casper 2.0 est planifié sur la durée du semestre selon une organisation progressive et partiellement itérative. La planification repose sur les lots principaux identifiés dans le WBS.

Les premières semaines sont consacrées à la prise en main du robot existant (Wikibot) et à l’analyse de l’architecture matérielle et logicielle. Les développements liés à l’interaction vocale, au suivi visuel et à l’interfaçage avec un chatbot sont ensuite menés en parallèle.
La conception mécanique et l’intégration des nouveaux composants sont réalisées de manière itérative afin de s’adapter aux contraintes identifiées au cours du projet.
Les dernières semaines sont dédiées à l’intégration globale, aux tests fonctionnels, à la validation du prototype et à la production des livrables.

Le diagramme de Gantt présenté ci-dessous illustre cette planification ainsi que les principaux jalons du projet.


Tableau des livrables :

Les livrables du projet Casper 2.0 sont à la fois scientifiques, techniques et organisationnels. Ils jalonnent l’avancement du projet et permettent de valider les différentes étapes de conception, d’intégration et de démonstration du prototype.

Le tableau ci-dessous présente les principaux livrables du projet, leur nature, leur description et leur date de remise prévisionnelle. Les dates indiquées sont susceptibles d’évoluer en fonction des contraintes techniques rencontrées au cours du projet.

Livrable | Nom | Type | Description | Échéance
L1 | Document de cadrage du projet | Organisationnel | Présentation du contexte, des objectifs, du cahier des charges synthétique, de la planification, de l’organisation de l’équipe et de l’analyse initiale des risques | Semaine 3
L2 | Cahier des charges fonctionnel | Scientifique / Technique | Définition des fonctions principales et contraintes du robot Casper 2.0 ainsi que des critères de validation | Semaine 3
L3 | Codes sources du projet | Technique | Code du système embarqué, des modules d’interaction vocale, de suivi visuel et d’interfaçage chatbot | Semaine 16
L4 | Fichiers de conception mécanique | Technique | Modèles CAO et fichiers d’impression 3D des pièces modifiées ou ajoutées | Semaine 16
L5 | Prototype final fonctionnel | Technique | Robot Casper 2.0 intégrant l’ensemble des fonctionnalités validées | Semaine 16

L6 | Dossier de conception | Scientifique / Technique | Description argumentée des choix techniques matériels et logiciels, en lien avec l’état de l’art | Semaine 16
L7 | Tutoriel Do-It-Yourself | Scientifique / Technique | Guide expliquant les étapes de réalisation et de reproduction du projet | Semaine 16
L8 | Vidéo de démonstration | CommunicationCourte vidéo illustrant le fonctionnement et les capacités | du robot | Semaine 16

Analyse initiale des risques :

Cette analyse vise à identifier les principaux risques techniques, organisationnels et externes susceptibles d’impacter le bon déroulement du projet Casper 2.0. Pour chaque risque identifié, une estimation de la probabilité et de l’impact est proposée, ainsi que des actions de prévention ou de mitigation.

Cette analyse sera mise à jour tout au long du projet en fonction de l’avancement et des difficultés rencontrées.

ID | Risque identifié | Type | Probabilité | Impact | Actions préventives
R1 | Indisponibilité ou panne du robot existant | Technique / Externe | Faible | Élevé | Vérification rapide de l’état du robot, sauvegarde des fichiers existants
R2 | Indisponibilité ou retard de livraison de composants matériels (caméra, carte audio) | Externe | Moyenne | Moyen | Anticipation des commandes, choix de composants standards
R3 | Modification ou indisponibilité du service de chatbot en ligne | Externe | Faible à moyenne | Moyen | Prévoir une solution alternative, tester plusieurs API
R4 | Limitation des performances matérielles de la carte Raspberry Pi | Technique | Moyenne | Moyen | Tests progressifs, optimisation logicielle

R5 | Contraintes d’accès aux salles ou au matériel du Fablab | Organisationnel / Externe | Faible | Moyen | Planification anticipée des séances
R6 | Problèmes de compatibilité entre bibliothèques logicielles externes | Technique | Moyenne | Moyen | Choix de solutions éprouvées, tests unitaires

## Conclusion :

Ce document de cadrage a permis de définir le cadre général du projet PRONTO Casper 2.0, en précisant le contexte, les objectifs, le cahier des charges fonctionnel, l’organisation de l’équipe ainsi que la planification prévisionnelle du projet.
Les principaux risques techniques et organisationnels ont été identifiés afin d’anticiper les difficultés potentielles et de mettre en place des actions de prévention adaptées.
La prochaine étape correspond à la phase 2 – Production. Cette phase consistera à prendre en main le robot existant (Wikibot), à démarrer les développements logiciels et matériels, et à réaliser les premières intégrations des nouvelles fonctionnalités. Un suivi régulier de l’avancement sera assuré afin d’adapter les choix techniques et la planification en fonction des contraintes rencontrées.
La phase 2 débutera par une prise en main complète du robot existant et le lancement des premiers développements logiciels et intégrations matérielles.

## Annexe :

Contrat d’équipe :
Le contrat d’équipe présenté ci-dessous a été établi lors de l’atelier « Former son équipe ». Il définit les règles de fonctionnement interne, les engagements des membres, les modalités de communication ainsi que la gestion des conflits et des absences au sein de l’équipe projet.


Cahier des charges fonctionnel : Le cahier des charges fonctionnel détaillé, présenté dans le document principal, définit les fonctions principales et contraintes du robot Casper 2.0 ainsi que les critères de validation associés.



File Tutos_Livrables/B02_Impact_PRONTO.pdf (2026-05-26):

IMT Atlantique
Projet PRONTO – S6 2025-2026 Campus de Brest


# PRONTO, S6 2025/2026 Equipe n°2: Casper 2.0

# Document d’étude d’impact

Version : 1.0
Date : 25 mars 2026

Auteur 1 : Garajeu Victor
Auteur 2 : Greillier Matthieu Auteur 3 : Lunven Nathan
Auteur 4 : Miannay Benjamin
Auteur 5 : Seillé Gautier
Encadré par : Lohr Christophe, Kerdreux Jerôme, Abiven Bernard

## Descriptif général du projet :

Le projet s’inscrit dans une démarche expérimentale en Interaction Humain-Robot (HRI), visant à transformer un robot déjà existant (Wikibot ou Casper), en un robot compagnon plus poussé, capable d’interactions naturelles. Le robot initial, bien que fonctionnel, se limitait à une interaction statique et purement informative sans perception visuelle de l’interlocuteur, ni gestuelle. La mission de notre équipe PRONTO est de doter ce robot de trois capacités majeures pour enrichir l’échange :
1. Une interaction vocale avancée, avec l’intégration d’un Chatbot en ligne permettant un dialogue ouvert en langage naturel, avec une capture audio performante jusqu’à 3 mètres.
2. Un suivi visuel, avec une détection et poursuite du visage de l’interlocuteur en temps presque réel pour maintenir un contact visuel.
3. Une gestuelle synchronisée, avec des animations des bras et de la tête du robot coordonnée avec la parole pour renforcer l’impression de présence et d’engagement.

## Objectif :

Pour mener à bien notre projet, nous l’avons décliné en quatre objectifs principaux, définis selon la méthode SMART, Spécifique (L'objectif doit être clair et précis), Mesurable (Comment saura-t-on que le but est atteint), Atteignable (L'objectif est-il ambitieux mais faisable), Réaliste (Avez-vous les ressources nécessaires), Temporel (Quelle est la date d'échéance) :

Objectif 1 : Interaction Vocale à distance

Critère | Application à notre objectif
Spécifique | Développer et intégrer un système de capture et de traitement audio capable de reconnaître des commandes vocales sans erreur majeure.
Mesurable | Obtenir un taux de reconnaissance correct supérieur à 95% lors de tests effectués à 3 mètres de distance, avec un bruit ambiant de 40-50 dB.
Atteignable | Oui, en utilisant un ou plusieurs microphone (réseau de microphones avec des technologies de Beamforming et de réduction de bruit), ce qui est standard pour cette distance.
Réaliste | Réaliste si le matériel choisi (microphone, API de reconnaissance vocale) est disponible et compatible avec l'environnement cible.
Temporel | Prototype fonctionnel et tests de portée validés pour le 2 juin 2026.

Objectif 2 : Suivi Visuel

Critère | Application à notre objectif
Spécifique | Implémenter un algorithme de détection et de suivi de visage (Face Tracking) capable de verrouiller la position de l'interlocuteur et d'ajuster l'angle de vue en conséquence.
Mesurable | Maintenir le visage de l'utilisateur dans le tiers central de l'image avec une latence inférieure à 1 seconde.
Atteignable | Oui, en utilisant le code fournit par nos encadrants, ainsi que nos recherches pour écrire le script qui réalise cette action.
Réaliste | Nécessite une caméra grand angle et un processeur capable de traiter le flux vidéo en continu, ainsi que d’un support motorisé pour effectuer les mouvements.
Temporel | Intégration de la brique logicielle et tests de fluidité terminés d'ici le 2 juin 2026.

Objectif 3 : Gestuelle du Robot

Critère | Application à votre objectif
Spécifique | Développer un système de contrôle moteur générant des mouvements (bras, tête) synchronisés dynamiquement avec le flux audio de la parole.
Mesurable | Atteindre une latence inférieure à 1s entre l'émission du son et le début du mouvement avec une trajectoire fluide.
Atteignable | Oui, en utilisant des bibliothèques d’animation en python et des bibliothèques procédurales analysant l’amplitude ou les phonèmes de la voix.
Réaliste | Réaliste si les servomoteurs ont une vitesse de réponse suffisante et si le contrôleur peut gérer l'audio et les PWM simultanément.
Temporel | Algorithmes de synchronisation validés pour le 2 juin 2026.

Objectif 4 : Livraison du Prototype

Critère | Application à votre objectif
Spécifique | Assembler et livrer un prototype physique complet intégrant les modules vocal, visuel et gestuel dans un châssis finalisé, modulable et autonome.
Mesurable | Réussir une démonstration continue de 5 minutes sans redémarrage, incluant au moins 5 interactions réussies (voix + suivi + gestes).
Atteignable | Oui, conditionné par la validation préalable des objectifs 1, 2 et 3 et une phase d’intégration rigoureuse.
Réaliste | Réaliste si l'environnement de test est contrôlé (sol plat, Wi-Fi stable).
Temporel | Livraison et présentation finale fixées au 2 juin 2026.

## Critères d’impact :

Les critères suivants permettent de caractériser les impacts majeurs du projet Casper 2.0 sur ses différents domaines d’influence.

1. Impacts pédagogiques et d’usage : Mesurent l’appropriation du robot par l’utilisateur final et l’acquisition de compétences techniques par l’équipe (maîtrise de nouvelles API, contrôle moteur).
2. Impacts économiques et logistique : Évaluent la viabilité financière de la mise à niveau (coût des composants vs gain de fonctionnalité) et la fiabilité opérationnelle du système (temps de déploiement, disponibilité).
3. Impacts écologiques : Évaluent la pollution émise lors du projet de quelque manière que ce soit (achat de nouveau matériel, impression 3D) et dans quelle mesure ce dernier s’inscrit dans une démarche responsable.
4. Impacts sociaux et sociétaux : Analysent la perception humaine du robot, incluant le niveau d’anthropomorphisme ressenti, l’inclusion numérique (compréhension des accents) et le sentiment de confidentialité vis-à-vis des capteurs (caméra/micro).

## Indicateurs de performance :

Pour évaluer ces critères, les indicateurs suivants ont été retenus pour leur pertinence direct avec le projet.

Critère | Indicateur | Méthode de calcul / Mesure | Justification de la pertinence
| | Réponses utiles Questions posées ×100 | Valide directement l’efficacité du chatbot et la qualité de la reconnaissance vocale à distance.
| | Chronométrage entre la fin de l'énoncé humain et le début de la réponse (voix + geste). | Indicateur clé du « temps quasi réel » ; une latence trop longue brise l'illusion naturelle.
| | Somme des factures des nouveaux composants (micro, caméra, moteurs). | Prouve l'efficience budgétaire de la stratégie de mise à jour plutôt que de rachat neuf.
| | Temps moyen de fonctionnement sans bug critique nécessitant un redémarrage. | Essentiel pour évaluer l'autonomie du robot dans un hall d'accueil sans supervision.
| | Ampères-heures (Ah) consommés sur une session active de 10 minutes. | Permet d'évaluer l'impact énergétique direct.
| | Estimation du volume de données (Go) transféré vers l'API du chatbot par heure. | Justifie le choix de l'API et mesure l'empreinte carbone réseau de l'IA.
| | Mesure de la distance à laquelle les utilisateurs s'arrêtent naturellement pour interagir. | Si la distance est < 3m, cela indique un défaut de performance audio/visuelle créant un inconfort.

Pédagogique &
Usage

Taux de complétion
des requêtes

Temps moyen de
latence perçue

Économique &
Logistique

Coût d'upgrade par
unité

Temps moyen de
fonctionnement
Écologique | Consommation électrique par cycle Volume de données Cloud
Social & Sociétal | Distance moyenne d'approche spontanée

## Protocole d’évaluation :

L’évolution de l’impact du projet suivra un protocole expérimental structuré en trois phases, réalisé en environnement intérieur contrôlé.

### 1. Phase de Tests Unitaires :

- Audio : Émission de 50 requêtes types à des distances échelonnées (1m, 2m, 3m) avec un bruit de fond de 45 dB. Enregistrement du taux de reconnaissance.
- Visuel : Déplacement latéral d’un sujet à vitesse constante devant le robot. Mesure de la latence de suivi via analyse vidéo (temps de réaction de la tête).
- Gestuelle : Vérification de la synchronisation sur des phrases types avec mesure du décalage audio-mouvement.

### 2. Phase d’intégration et fiabilité :

- Lancement du robot en autonomie totale.
- Exécution de cycles répétés de 5 minutes jusqu’à apparition d’un bug..
- Relevé précis du temps de fonctionnement.

### 3. Phase d’usage réel (tests utilisateurs) :

- Invitation d’un panel de 20 utilisateurs variés (âge, accent, familiarité avec la technologie).
- Consigne : « Interagissez naturellement avec le robot ».
- Observation discrète pour mesurer la distance d’approche spontanée.

## Finalités du commanditaire :

Le commanditaire, l’équipe de recherche RAMBO de l’IMT Atlantique, poursuit deux finalités majeures.

Faire avancer la recherche en Interaction Humain-Robot (HRI) : Le besoin fondamental est de disposer d’une plate-forme physique capable de simuler une présence naturelle. Cet outil est indispensable pour mener des études comportementales fines, telles que l’évaluation de la perception d’intrusion ou de réassurance chez l’utilisateur, ou encore l’analyse des facteurs d’acceptabilité des robots compagnons.

Pérenniser et faire évoluer une plateforme matérielle existante : Au-delà de l'aspect scientifique, une finalité économique et logistique guide le projet : démontrer qu’il est possible d’augmenter significativement les capacités d’un système (ajout de vision, de gestuelle, d'IA) tout en maîtrisant le coût de revient de la mise à niveau (upgrade) et en favorisant l’économie circulaire via la réutilisation du châssis Wikibot.

## Finalités de l’équipe et compatibilité :

De notre côté, notre équipe porte trois finalités distinctes mais liées :

1. Acquisition et validation de compétences d’ingénierie : La finalité première reste l’apprentissage. L’équipe vise la maîtrise de briques technologiques complexes et actuelles : traitement du signal audio (Beamforming), algorithmes de suivi de visage en temps réel, synchronisation procédurale des moteurs et intégration d’API de langage naturel.
2. Livraison d’un produit démonstratif sous contrainte temporelle : L’objectif pragmatique est d’aboutir à un prototype physique fonctionnel, capable de réussir une démonstration continue de 5 minutes sans erreur, validant ainsi notre capacité à gérer un projet de bout en bout dans les temps impartis.
3. Application des principes de l’Ingénierie Responsable : En accord avec les valeurs de l’IMT Atlantique, l’équipe s'engage à intégrer des critères écologiques dès la conception : optimisation de l’efficacité énergétique, minimisation du poids carbone des requêtes Cloud et conception pour la réparabilité.

Analyse de la compatibilité :

Les finalités de notre équipe sont totalement compatibles et synergiques avec celles du commanditaire :

- Synergie technique : Le besoin de l’équipe RAMBO de disposer d’une plateforme HRI performante pour ses études de sociabilité offre à l’équipe étudiante le cas d’usage parfait pour implémenter et tester ses algorithmes d'IA et de contrôle moteur. La rigueur scientifique attendue par le chercheur garantit la qualité de l'apprentissage de l'étudiant.
- Alignement éthique et économique : La volonté de l’équipe étudiante de minimiser l’empreinte carbone (via l’optimisation du code et le choix de composants légers) rejoint directement la contrainte du commanditaire d’utiliser du matériel existant et d’optimiser les coûts. L'approche "économie circulaire" est donc un point de convergence naturel.
- Convergence temporelle : L’échéance de démonstration fixée au 2 juin, vitale pour la validation académique de l'équipe, garantit simultanément au commanditaire la livraison d’un système testable et opérationnel pour ses propres travaux de recherche futurs.

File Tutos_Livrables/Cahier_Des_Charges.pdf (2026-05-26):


IMT Atlantique

Projet PRONTO – S6 2025-2026

Campus de BREST

Auteurs : | Encadré par :
Matthieu Greillier | Christophe Lohr
Gautier Seillé | Jérôme Kerdreux
Nathan Lunven | Bernard Abiven

Benjamin Miannay

Victor Garajeu

# PRONTO, S6 2025/2026

# Equipe n°2: Casper 2.0

# Modèle de cahier des charges fonctionnel

Date 26/01/2026

## Table des matières

## Table des matières

### 1 Introduction

### 1.1 Objet du document

Ce document constitue le cahier des charges fonctionnelle du projet PRONTO : Robots compagnon : Casper 2.0, réalisé dans le cadre du semestre S6 2025/2026 à IMT Atlantique (sur le campus de Brest).

Il vise à formaliser le besoin exprimé par le client (ici nos encadrants), à identifier les fonctions de service et de contrainte attendues du système, ainsi que les critères permettant de valider la solution proposée.

### 1.2 Documents en référence

Les différents documents de référence que nous avons utilisés sont regroupés dans le tableau ci dessous :

Identifiant | Référence du document
[1] « Plan type dossier de conception », Techniques de l’Ingénieur. Consulté le: 25 novembre 2024. [En ligne]. | Disponible sur: https://www.techniques-ingenieur.fr/fiche-pratique/innovation-th10/deployer-l-innovation-dt30/concevoir-les-architectures-fonctionnelle-et-physique-des-systemes-comp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 (https://www.techniques-ingenieur.fr/fiche-pratique/innovation-th10/deployer-l-innovation-dt30/concevoir-les-architectures-fonctionnelle-et-physique-des-system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)
[2] L. Bonduelle, C. Feltin, F. Thollot, A. Marion. « WIKIBOT - projet PRONTO » | https://github.com/AstridMarion/projet-pronto
[3] W. Cogley. « Camera-Eye Follower Bot » https://www.notion.so/nilheim- | mechatronics/Camera-Eye-Follower-Bot-25524779b64d80969680f8a0c32fa703 (https://www.notion.so/nilheim-mechatronics/Camera-Eye-Follower-Bot-25524779b64d80969680f8a0c32fa703)

### 1.3 Terminologie

Terme | Abréviation | Description
Human-Robot Interaction | HRI | Discipline qui s’intéresse aux facteurs qui peuvent amener un humain à interagir avec un système robotique
Utilisateur | — | Personne interagissant avec le robot
Fonction Principale | FP | Fonction principale du robot
Fonction de contrainte | FC | Fonction liée aux contraintes de l’environnement

### 2 Présentation du système

### 2.1 Finalité, mission, objectifs

Finalité

Le système vise à expérimenter les relations Humains-Robots en essayant d’humaniser le plus possible le robot. En effet, ce dernier doit être capable de regarder son interlocuteur dans les yeux et de bouger les bras tout en s’adressant à lui. L'interaction qui est ici mise en place est vocale et le robot fait appel à un chatbot afin d’être capable d’assurer une réelle discussion contrairement à ce dont il était capable auparavant. En effet, il ne pouvait que renvoyer la définition d’un mot donné à l’aide de Wikipédia. Ce projet s’inscrit dans une démarche expérimentale dans le cadre des interactions Humains-Robots afin de savoir si un robot est capable de tenir une discussion avec un Humain tout en faisant en sorte que les deux puissent se faire face comme dans une discussion traditionnelle entre deux Humains. Le robot doit également être capable de présence physique.

Mission

Notre première mission est de faire évoluer le prototype déjà existant du robot. Le système devra ensuite être capable d'interagir avec son interlocuteur en faisant appel à une solution de chatbot en ligne telle que ChatGPT ou Gemini tout en étant capable de bouger les bras ou bien la tête simultanément. Il doit également être capable de suivre son interlocuteur en tournant la tête vers celui-ci à l’aide d’une caméra. Enfin, il doit être capable de détecter facilement lorsqu'un interlocuteur lui adresse la parole et de produire ensuite un son de qualité.

Objectifs

Le robot doit être en mesure de capter la discussion et de tenir cette dernière à une distance de 3 mètres.

### 2.2 Liste des parties prenantes

Partie prenante | Rôle | Contact (le cas échéant)
Client (Équipe RAMBO) | Commande du produit | christophe.lohr@imt-atlantique.fr
Utilisateurs | Interagit avec le robot | christophe.lohr@imt-atlantique.fr
Equipe de création (Équipe PRONTO) | Création du produit | matthieu.greillier@imt-atlantique.net victor.garajeu@imt-atlantique.net
Encadrants PRONTO | Encadrement scientifique et technique | christophe.lohr@imt-atlantique.fr

### 2.3 Contexte d’utilisation du système

Le projet Casper 2.0 s’inscrit dans le domaine de la Robotique Sociale et de l’Interaction Humain-Robot (HRI). Le but est de transformer un automate informationnel (Wikibot) en un compagnon capable de présence physique. Il est destiné à être utilisé dans des environnements intérieurs (bureaux, laboratoires, domiciles) afin de pouvoir réaliser des discussions vivantes.


Figure 1 : Le système dans son environnement. Diagramme de contexte. Graphe d'interaction du système.

### 3 Expression fonctionnelle du besoin

### 3.1 Fonctions de service et de contrainte

Figure 2 : Représentation graphique des fonctions de service et de contraintes du système avec l’environnement général


Tableau 1. Tableau des fonctionnalités, avec leur(s) critère(s) de valeur, leur niveau(x), leur flexibilité et leur priorité. FP : fonction principale, FS : fonction secondaire, FC : fonction de contraintes.

Fonction | Critère(s) | Niveau(x) | Flexibilité | Priorité

FP1 – Émettre et capter du son

FP1.1 – Capter le son de l'utilisateur | Détection automatique de la parole | Son perçu à 3m de distance | Nulle | 1
| Doit pouvoir fonctionner dans un environnement avec du bruit | Compréhension de la consigne dans une salle animée | Forte
FP1.2 – Comprendre la requête de l’utilisateur | Taux de retranscription correcte | 75% de requête comprises | Nulle | 1
FP1.3 – Emettre un son audible | Le son doit être audible | Audible à 3m de distance | Nulle | 1
| Le son doit être entendu par une personne malentendante | Son à 40 dB minimum à 3m | Forte

FP2 – Le robot doit paraître plus vivant

FP2.1 - La tête du robot
doit suivre l’interlocuteur

La tête tourne de
manière fluide avec le
déplacement

Temps de latence
de 1s, angle de
180°
Nulle | 1

FP2.2 - Les bras du robot
doivent bouger de manière
fluide

Les bras doivent bouger
pendant la parole du
robot

2 degrés de
liberté
Moyenne | 2

FP3 - Utiliser un chatbot

Communiquer via un
chatbot

Doit interfacer avec un
chatbot (Gémini,
ChatGPT …)

Echange
fonctionnel avec
un service
externe
Nulle | 1

FC1 - S’alimenter

Le système doit
s’alimenter

Le système doit
pouvoir
fonctionner
Nulle | 1

FC2 - Être ergonomique

Le robot doit être
ergonomique

Eviter les fils
apparents
Forte | 3

### 3.2 Scénarios

Le produit va être utilisé pour discuter à une distance d’au plus 3 mètres, en intérieur. Si aucun son n’est capté ou si la connexion visuelle avec l’interlocuteur est perdue pendant un certain temps, le robot se déconnecte automatiquement.

Les différentes fonctionnalités s'enchaînent en parallèle afin d’assurer une fluidité maximale.

Afin d’utiliser le robot, il suffit à l’utilisateur de parler à distance raisonnable. Il pourra alors tenir la conversation par la suite.

### 4 Validation du besoin

La validation du besoin reposera sur des démonstrations expérimentales du prototype. Chaque fonction principale sera testée à l’aide de scénarios d’usage définis précédemment. Les critères de performance indiqués dans le tableau des fonctions serviront de métriques objectives pour valider ou non la conformité du système aux exigences du client.

La fonction principale d'interaction vocalement avec un utilisateur sera validée en soumettant au robot une série de requêtes vocales prédéfinies émises par un utilisateur situé à une distance comprise entre 0,5 m et 3 m. La fonction sera considérée comme validée si le taux de compréhension des requêtes est supérieur ou égal à 75%.

La fonction principale du suivre visuellement l’utilisateur de suivi visuel sera validée en demandant à un utilisateur de se déplacer latéralement devant le robot. La fonction sera validée si le robot oriente correctement sa tête vers l’utilisateur avec un temps de réaction inférieur à 1 seconde.

### 5 Conclusion

Le présent cahier des charges fonctionnel a permis de formaliser les fonctions principales et contraintes du robot compagnon Casper 2.0. L’objectif est de proposer une interaction humanoïde naturelle reposant sur une combinaison d’interaction vocale, de perception visuelle et d’animation gestuelle.

Les exigences définies tiennent compte des contraintes matérielles de la plate-forme existante, notamment l’utilisation d’une Raspberry Pi comme unité de calcul embarquée. Une attention particulière devra être portée aux performances temps réel du système afin de garantir une interaction fluide et acceptable pour l’utilisateur.
Le document met également en évidence la nécessité d’une approche progressive et adaptable, notamment en ce qui concerne l’intégration des briques de reconnaissance vocale, de traitement conversationnel et de synthèse vocale. Des solutions alternatives devront être envisagées si les performances embarquées s’avèrent insuffisantes.

Ce cahier des charges constituera la référence pour la phase de production et pour les validations expérimentales à venir.

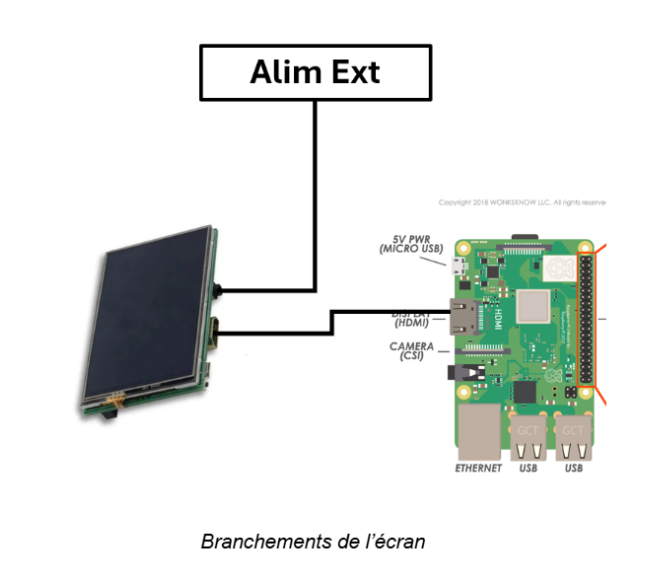
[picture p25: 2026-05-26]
images/Branchement_Ecran.png

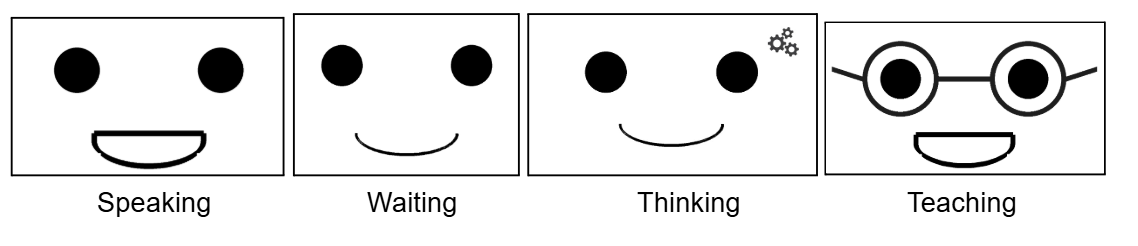
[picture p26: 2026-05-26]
images/Expressions.png

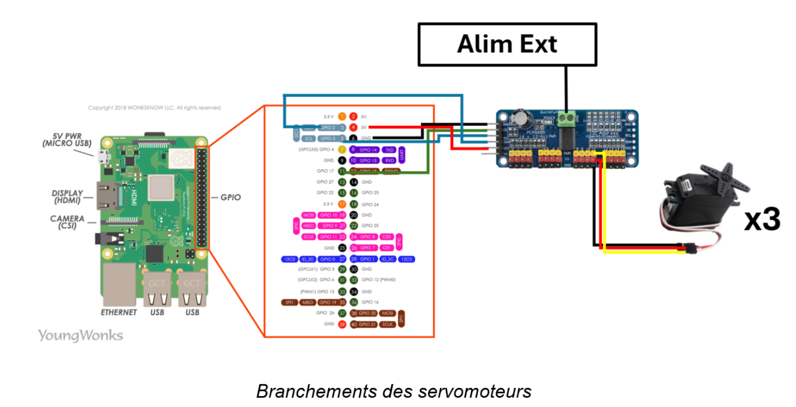
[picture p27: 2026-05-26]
images/Branchement_Servomoteurs.png

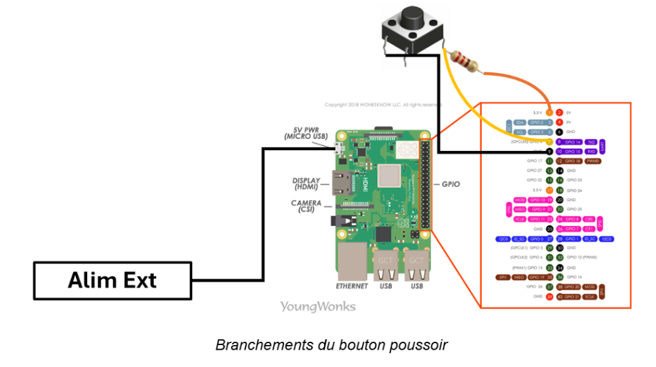
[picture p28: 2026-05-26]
images/Branchement_Bonton-poussoir.png

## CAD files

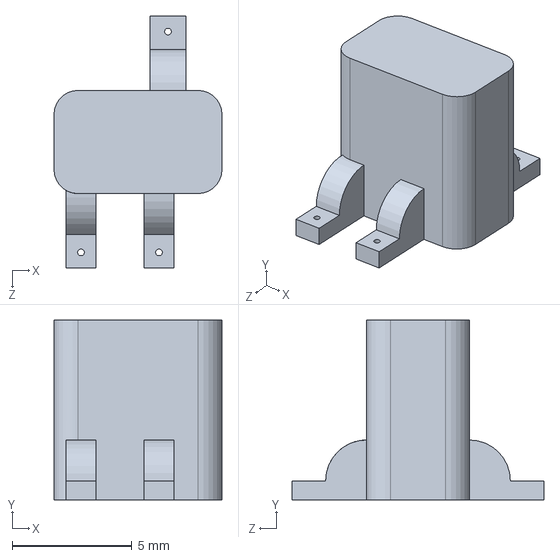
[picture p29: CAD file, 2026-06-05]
impression-3D/support tete vf.SLDPRT
7.00 x 7.50 x 10.5 mm

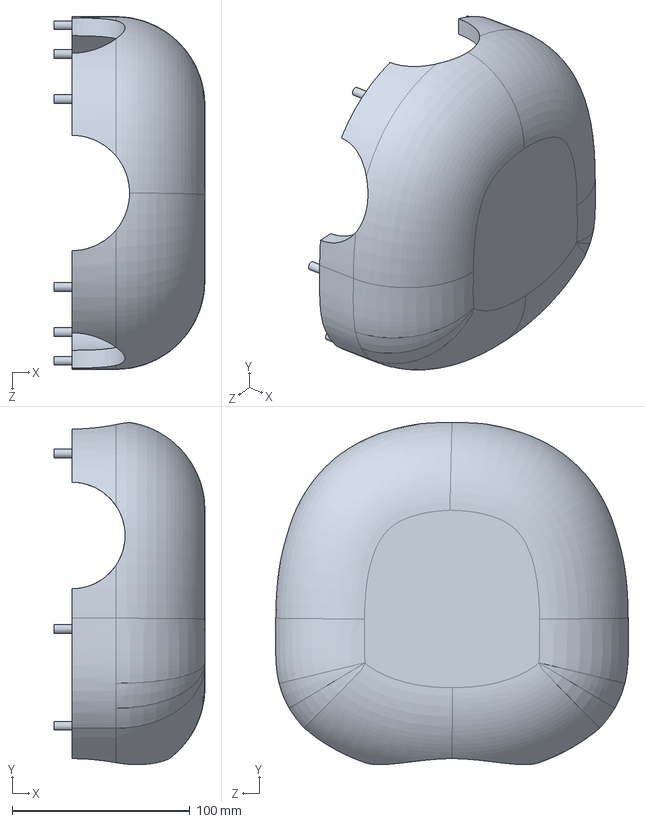
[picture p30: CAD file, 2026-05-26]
impression-3D/CorpsArrière.SLDPRT
85.0 x 192.8 x 198.8 mm

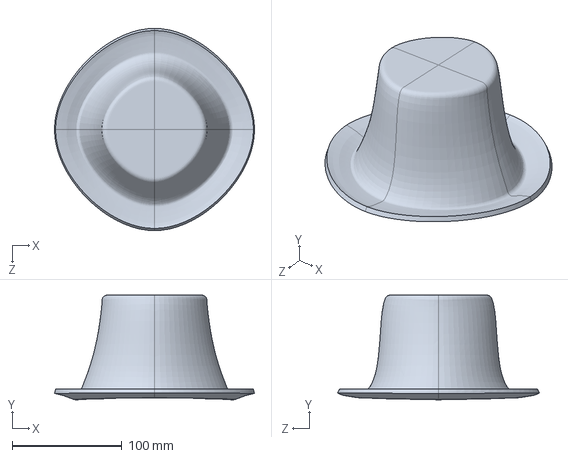
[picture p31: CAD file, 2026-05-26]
impression-3D/chapeau.SLDPRT
181.9 x 95.4 x 183.9 mm

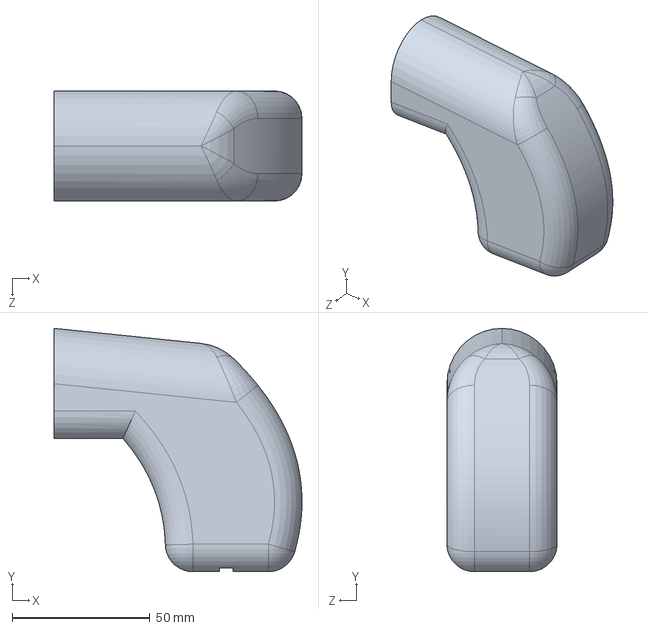
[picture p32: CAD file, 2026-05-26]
impression-3D/bras2_0.SLDPRT
90.0 x 88.3 x 40.0 mm

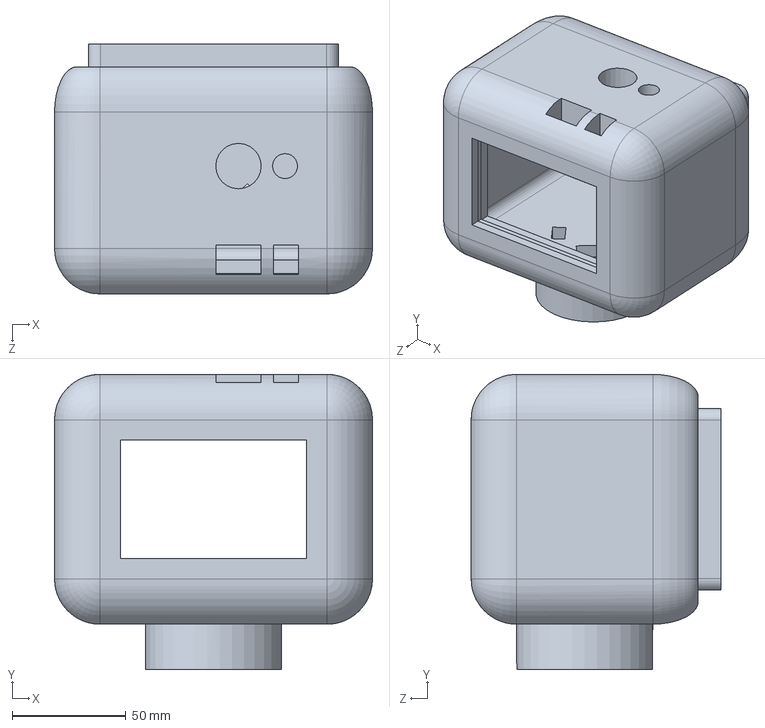
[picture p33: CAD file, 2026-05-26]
impression-3D/Tête.SLDPRT
140.0 x 130.0 x 110.0 mm

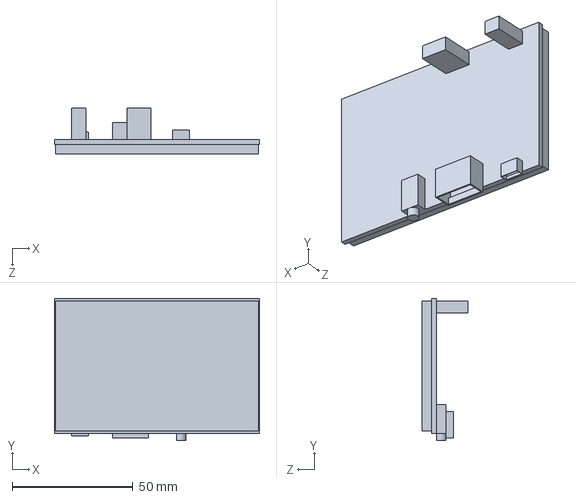
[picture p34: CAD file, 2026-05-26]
impression-3D/Ecran.SLDPRT
85.0 x 59.0 x 19.0 mm

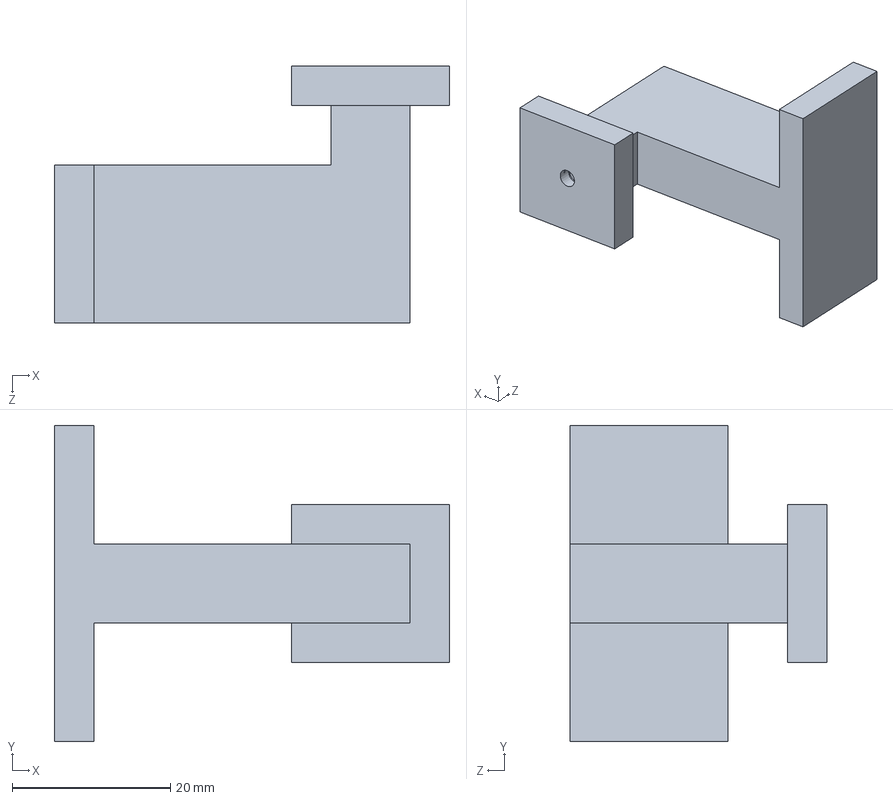
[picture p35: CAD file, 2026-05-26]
impression-3D/Ailette.SLDPRT
50.0 x 40.0 x 32.5 mm

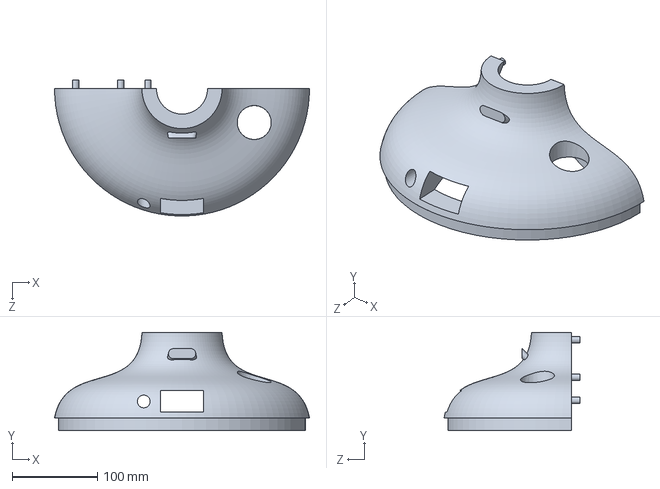
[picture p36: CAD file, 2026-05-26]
impression-3D/SocleArrière.SLDPRT
300.0 x 115.5 x 159.9 mm

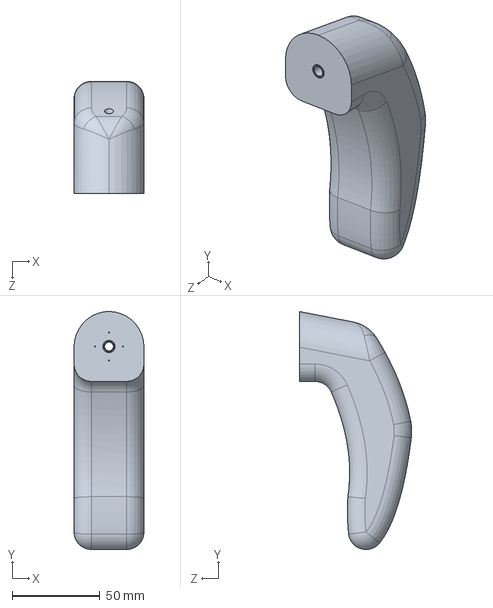
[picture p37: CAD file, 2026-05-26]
impression-3D/Bras.SLDPRT
40.0 x 136.0 x 64.3 mm

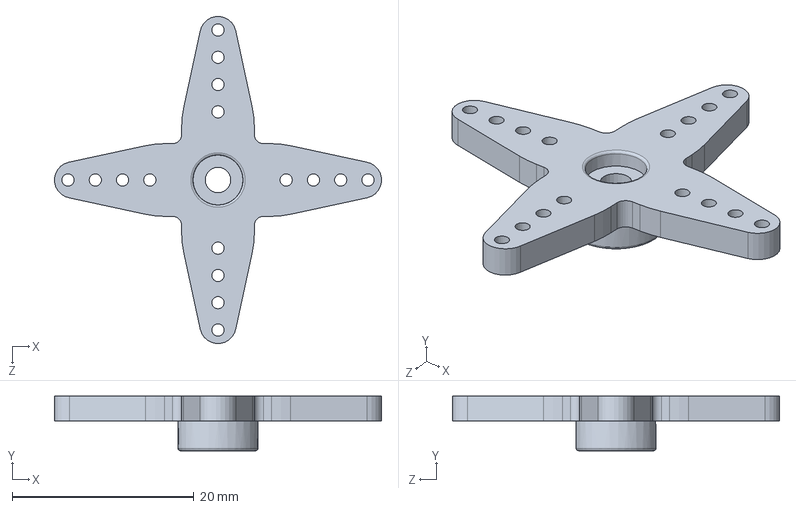
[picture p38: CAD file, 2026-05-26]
impression-3D/Etoile 4 servo_2024.SLDPRT
36.0 x 6.00 x 36.0 mm

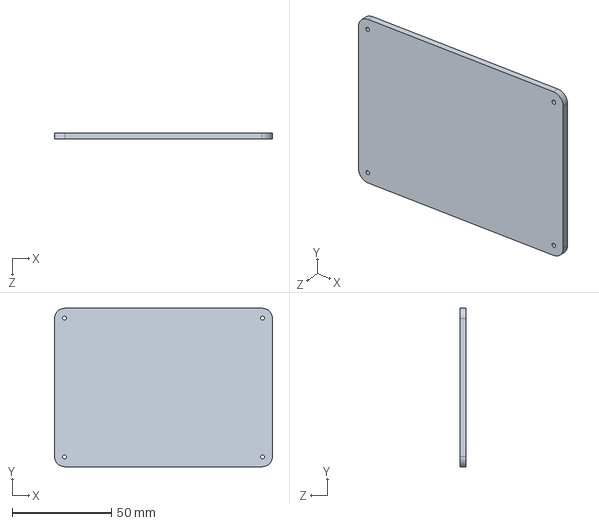
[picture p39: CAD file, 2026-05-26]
impression-3D/FermetureTete.SLDPRT
110.0 x 80.0 x 3.00 mm

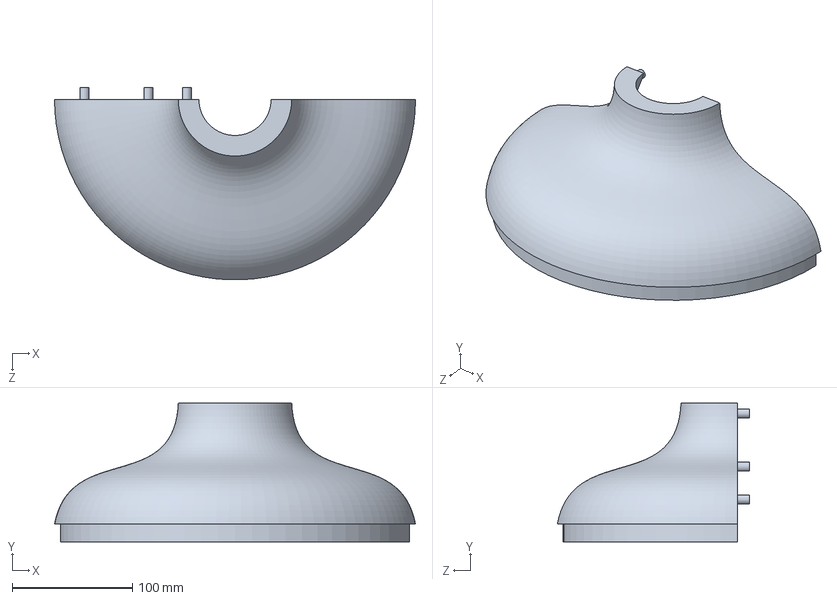
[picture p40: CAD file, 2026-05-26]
impression-3D/SocleFace.SLDPRT
300.0 x 115.5 x 159.9 mm

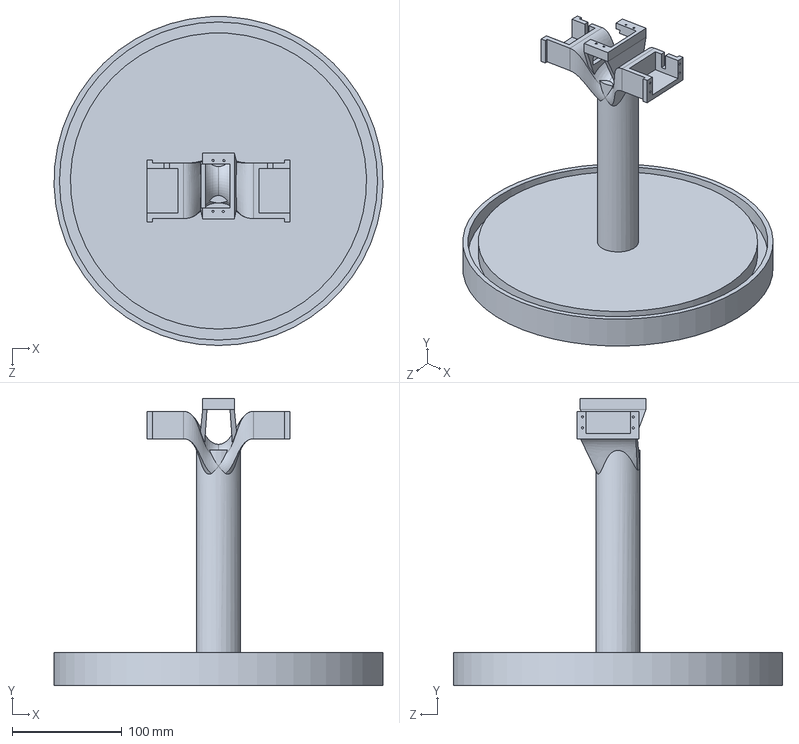
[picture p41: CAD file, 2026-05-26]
impression-3D/Armature.SLDPRT
299.9 x 261.8 x 300.0 mm

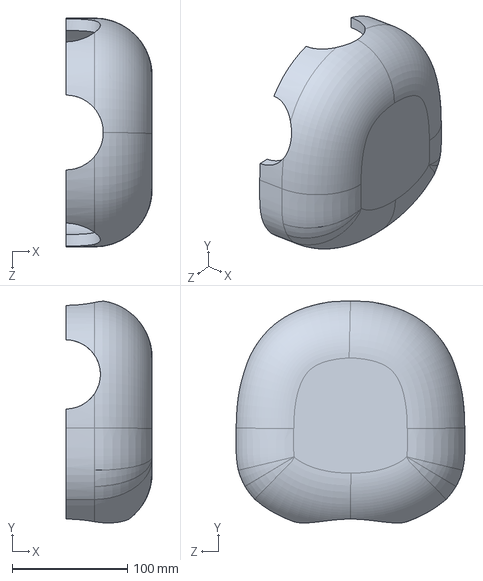
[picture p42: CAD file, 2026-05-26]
impression-3D/CorpsAvant.SLDPRT
75.0 x 192.8 x 198.8 mm

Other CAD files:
impression-3D/Servomoteur.SLDPRT

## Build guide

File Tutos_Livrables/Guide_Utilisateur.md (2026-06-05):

#Casper 2.0 – Robot interactif
#Installation

##Prérequis
- Raspberry Pi 4 avec Raspberry Pi OS 64-bit
- Connexion Internet
- Accès SSH ou écran + clavier
- Caméra, ReSpeaker Pi HAT, servomoteurs

##Procédure d'installation

1. Connexion SSH :
   ```bash
   ssh grp10@rpi.local

2. Cloner le projet :
git clone https://github.com/VictorGrj/Projet_PRONTO_CASPER2.0.git
cd Projet_PRONTO_CASPER2.0

3. Créer l'environnement virtuel :
python3 -m venv venv
source venv/bin/activate

4. Installer les dépendances Python :
pip install --upgrade pip
pip install -r requirements.txt

5. Installer les dépendances système :
sudo apt install portaudio19-dev libasound2-dev python3-opencv

6. Activer I2C :
sudo raspi-config
Naviguez vers : Interface Options → I2C → Enable

7. Lancer le projet :
python Main.py

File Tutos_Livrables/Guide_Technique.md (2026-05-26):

#Guide technique – Casper 2.0

##Présentation

Ce document décrit l’architecture matérielle et logicielle du robot Casper 2.0 ainsi que son fonctionnement global.
Il a pour objectif de permettre à un utilisateur ou futur développeur de comprendre et reproduire le système.

---

#1. Organisation du système

Le robot repose sur une architecture embarquée autour d’une Raspberry Pi 4.

### Modules principaux :

- Interaction vocale (Vosk + Gemini + Piper)
- Suivi visuel (OpenCV)
- Contrôle moteurs (PCA9685 + servomoteurs)
- Interface visuelle (Pygame)

---

# 2. Composants électroniques

## Matériel utilisé

- Raspberry Pi 4 Model B
- Caméra Raspberry Pi
- ReSpeaker Pi HAT (micro + audio)
- Écran LCD (affichage visage)
- Servomoteurs (bras + tête)
- Module PCA9685 (contrôle PWM)
- Bouton poussoir
- Résistance 1 kΩ

---

## Interfaces matérielles

- GPIO 4 → Bouton poussoir
- GPIO 17 → Contrôle servomoteurs (OE)
- I2C → PCA9685 (servomoteurs + bus)

---

# 3. Architecture logicielle

Le code est écrit en Python et repose sur un système multi-thread.

## Modules principaux

| Module | Rôle |
|---|---|
| `Main.py` | Orchestration globale + machine à états |
| `AudioProcessing.py` | Capture audio + reconnaissance + IA |
| `Speak.py` | Lecture des fichiers audio |
| `CameraTracking.py` | Suivi visuel |
| `Servo.py` | Contrôle des moteurs |
| `Screen.py` | Interface graphique |

---

# 4. Fonctionnement global

## Cycle d’interaction

1. L’utilisateur appuie sur le bouton
2. Le micro enregistre la voix
3. Vosk transforme la voix en texte
4. Gemini génère une réponse
5. Piper transforme le texte en audio
6. Le robot parle et bouge

---

## États du robot

- `waiting` → attente utilisateur
- `thinking` → traitement IA
- `speaking` → réponse audio
- `teaching` → explication
- `idle` → repos

---

# 5. Suivi visuel

Le module `CameraTracking.py` utilise :

- OpenCV
- Haar Cascade (détection de visage)
- Calcul du centre du visage
- Correction du servo moteur de la tête

Objectif : garder l’utilisateur centré dans le champ de vision.

---

# 6. Contrôle des servomoteurs

## Carte utilisée

- PCA9685 (I2C)
- Permet de gérer plusieurs servomoteurs en PWM

## Mouvements

- Bras gauche
- Bras droit
- Tête (tracking visage)

Les mouvements sont simplifiés pour éviter une surcharge CPU.

---

# 7. Système audio

## Entrée audio

- ReSpeaker Pi HAT
- Capture du signal audio
- Activation via bouton poussoir

## Traitement

- Vosk → transcription texte
- Gemini → génération réponse IA

## Sortie audio

- Piper TTS
- Lecture du fichier `.wav`

---

# 8. Interface graphique

- Bibliothèque : `pygame`
- Affichage des expressions du robot :

| Mode | Description |
|---|---|
| waiting | attente utilisateur |
| thinking | traitement IA |
| speaking | parole |
| teaching | explication |

---

# 9. Problèmes rencontrés

- Limitation CPU Raspberry Pi
- Latence du suivi visuel
- Bruit moteur perturbant le micro
- Limites API Gemini
- Reconnaissance vocale sensible au bruit

---

# 10. Améliorations possibles

- Passage à Raspberry Pi 5
- Remplacement Haar Cascade → MediaPipe
- Ajout mémoire conversationnelle
- Activation vocale (wake word)
- Amélioration fluidité des servomoteurs

---

# Conclusion

Casper 2.0 est un robot interactif complet combinant :

- Vision
- Audio
- Intelligence artificielle
- Mécanique embarquée

Il constitue une plateforme expérimentale de robot compagnon interactif.

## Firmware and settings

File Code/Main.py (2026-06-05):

################################################################################################################################
################################################# IMPORTS ######################################################################
################################################################################################################################
# ---------- Audio ----------
from audio.AudioProcessing import AudioProcessing as Audio
from audio.Speak import Speak

# ---------- Screen ----------
from screen.Screen import Screen
import pygame

# ---------- Servo ----------
from servo.Servo import Servo
from adafruit_servokit import ServoKit

# ---------- Camera Tracking ----------
from camera.Tracking import CameraTracking

# ---------- Others ----------
import time
import os

class Main:
    """
    Cette classe principale orchestre l'ensemble des threads pour faire interagir le robot avec l'utilisateur.
    """

    def __init__(self):
        "Constructeur de la classe"
        self.running = True

        # Écran (Thread permanent)
        self.screen = Screen(mode="speaking")
        self.screen.start()
        
        # Suivi de tête (Thread permanent)
        self.tracker = CameraTracking()
        self.kit = ServoKit(channels=16)
        self.kit.servo[3].angle = 10
        self.kit.servo[7].angle = 10

    def start(self):
        """Gestionnaire d'événements et boucle principale."""

        print("START robot")
        self.tracker.start()

        try:
            # -------- Introduction (hello/tuto) --------
            OUTPUT_PATH = os.path.join(os.path.dirname(__file__), ".", "audio", "preRecordedDialogs","hello.wav")
            audioHello = Speak(OUTPUT_PATH)
            servoR = Servo("rightArm", self.kit)
            servoL = Servo("leftArm", self.kit)

            audioHello.start()
            servoR.start()
            servoL.start()

            # Attente stricte de la fin de l'intro
            while self.running:
                if not audioHello.is_alive():
                    audioHello.stop()
                    servoR.stop()
                    servoL.stop()
                    self.running = False
                time.sleep(0.1)

            # --- Pause de sécurité pour la carte audio ---
            time.sleep(0.5)

            # -------- BOUCLE PRINCIPALE DE DIALOGUE --------
            while True:
                try: 
                    self.running = True

                    self.screen.change_mode("speaking")
                    OUTPUT_PATH = os.path.join(os.path.dirname(__file__), ".", "audio", "preRecordedDialogs","youCanSpeak.wav")
                    audioYouCanSpeak = Speak(OUTPUT_PATH)
                    
                    audioYouCanSpeak.start()
                    audioYouCanSpeak.join() # On attend impérativement qu'il finisse de parler
                    audioYouCanSpeak.stop()
                    
                    # On laisse 0.5s à Linux pour relâcher complètement la carte son
                    time.sleep(0.5)
                    
                    # 2. Le robot écoute -> Mode waiting
                    self.screen.change_mode("waiting")
                    audio = Audio()
                    audio.start()

                    while self.running:
                        # Passage en mode "thinking" dès que l'utilisateur relâche le bouton
                        if not audio.getUserSpeak():
                            self.screen.change_mode("thinking")

                        # Fin du traitement Vosk + Gemini
                        if not audio.is_alive():
                            audio.stop()
                            audio.join()
                            self.running = False

                        time.sleep(0.1)

                    # -------- 3. PHASE DE PAROLE & MOUVEMENT DES BRAS --------
                    self.running = True
                    print("getAnswer=", audio.getAnswer())
                    
                    if audio.getAnswer() is None:  # CAS 1 : Le robot ne sait pas
                        self.screen.change_mode("speaking")
                        OUTPUT_PATH = os.path.join(os.path.dirname(__file__), ".", "audio", "preRecordedDialogs","dontKnow.wav")
                        speak_task = Speak(OUTPUT_PATH)
                        
                        # On instancie la tête ET les bras
                        servoH = Servo("head", self.kit)
                        servoR = Servo("rightArm", self.kit)
                        servoL = Servo("leftArm", self.kit)

                        speak_task.start()
                        servoH.start()
                        servoR.start()
                        servoL.start()

                        while self.running:
                            if not speak_task.is_alive():
                                speak_task.stop()
                                servoH.stop()
                                servoR.stop()
                                servoL.stop()
                                self.running = False
                            time.sleep(0.1)

                    else:  # CAS 2 : Le robot répond (Gemini)
                        self.screen.change_mode("teaching")
                        OUTPUT_PATH = os.path.join(os.path.dirname(__file__), ".", "audio", "answer.wav")
                        speak_task = Speak(OUTPUT_PATH)
                        
                        # On instancie les deux bras
                        servoR = Servo("rightArm", self.kit)
                        servoL = Servo("leftArm", self.kit)
                        
                        speak_task.start()
                        servoR.start()
                        servoL.start()

                        while self.running:
                            if not speak_task.is_alive():
                                speak_task.stop()
                                servoR.stop()
                                servoL.stop()
                                self.running = False
                            time.sleep(0.1)
                    
                    # Petite pause avant de relancer le cycle complet
                    time.sleep(0.5)

                except OSError as err:
                    # Si le suivi de visage et les bras rentrent en collision sur l'I2C, 
                    # on intercepte l'erreur pour que le script ne s'éteigne pas 
                    print(f"\n[I2C IGNORED] Micro-coupure du bus I2C ({err}). Le robot respire et continue !\n")
                    time.sleep(0.5)
                    self.running = False 
                    continue

        except Exception as e:
            print(f"Error in the main event loop: {e}")
            self.tracker.stop()

if __name__ == "__main__":
    robot = Main()
    robot.start()

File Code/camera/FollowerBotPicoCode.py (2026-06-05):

import time
from machine import Pin, ADC
from servo import Servo
from picozero import Button
import random
import sys
import select

# Set up the switches and potentiometers
enable = Pin(6, Pin.IN, Pin.PULL_UP)
mode = Pin(7, Pin.IN, Pin.PULL_UP)
blink_pin = Pin(9, Pin.IN, Pin.PULL_UP)
led = Pin(25, Pin.OUT)
UD = ADC(26)
trim = ADC(27)
LR = ADC(28)

# Motion tracking parameters
deadzone_eye = 25
deadzone_neck = 20
neck_timer_ms = 1200
neck_trigger_time = 0
neck_flag = False
neck_x_map = 1.25
neck_y_map = 1
Kp = 0.03
last_update = time.ticks_ms()
error_x = 0
error_y = 0

# Define servos
servos = {
    "LR": Servo(pin_id=10),
    "UD": Servo(pin_id=11),
    "TL": Servo(pin_id=12),
    "BaseX": Servo(pin_id=13),
    "TR": Servo(pin_id=14),
    "BaseY": Servo(pin_id=15),
}

# Min, Max, target
servo_limits = {
    "LR": (40, 140),   
    "UD": (40, 140),
    "TL": (90, 170),
    "BaseX": (10, 170),
    "TR": (90, 10),
    "BaseY": (40, 140),
}

servo_targets = {
    "LR": 90,
    "UD": 90,
    "BaseX": 90,
    "BaseY": 90,
    "BXTarget":90,
    "BYTarget":90,
}

# Set all servos to central position for assembly
def calibrate():
    for name, servo in servos.items():
        servo.write(90)


def blink():
    servos["TL"].write(90)
    servos["TR"].write(90)

def lid_sync():
    ud_min, ud_max = servo_limits["UD"]
    tl_min, tl_max = servo_limits["TL"]
    tr_min, tr_max = servo_limits["TR"]

    # Normalize UD position to a 0-1 range
    ud_progress = (servo_targets["UD"] - ud_min) / (ud_max - ud_min)  # 0 (min) → 1 (max)

    # Find target positions
    tl_target = tl_max - ((tl_max - tl_min)*(0.5*(1-ud_progress)))-10
    tr_target = tr_max + ((tr_min - tr_max)*(0.5*(1-ud_progress)))+10

    servos["TL"].write(tl_target)
    servos["TR"].write(tr_target)

def flash():
    led.value(not led.value())
    time.sleep(0.2)
    led.value(not led.value())
    time.sleep(0.2)
    led.value(not led.value())
    time.sleep(0.2)
    led.value(not led.value())
    time.sleep(0.2)



def move_target(servo, error):
    if abs(error) <= deadzone_eye:
        return
    if error < 0:
        error = error - deadzone_eye
    elif error < 0:
        error = error + deadzone_eye

    step = int(Kp * error)
    if step == 0:
        step = 1 if error > 0 else -1

    new_target = servo_targets[servo] + step
    new_target = max(servo_limits[servo][0], min(servo_limits[servo][1], new_target))
    servo_targets[servo] = new_target

    servos[servo].write(new_target)

def neck_target(LR, UD):
    servo_targets["BXTarget"] = LR
    servo_targets["BYTarget"] = 90 - ((90 - UD) * 0.6) 



def neck_smooth_move(speed_deg_per_s=60):
    """Smoothly move BaseX and BaseY toward their targets at a fixed speed in deg/s."""
    global last_update
    now = time.ticks_ms()
    dt = time.ticks_diff(now, last_update)
    last_update = now

    step_size = (speed_deg_per_s * dt) / 1000.0

    # BaseX
    dx = servo_targets["BXTarget"] - servo_targets["BaseX"]
    if abs(dx) <= step_size:
        servo_targets["BaseX"] = servo_targets["BXTarget"]
    else:
        servo_targets["BaseX"] += step_size if dx > 0 else -step_size

    # BaseY
    dy = servo_targets["BYTarget"] - servo_targets["BaseY"]
    if abs(dy) <= step_size:
        servo_targets["BaseY"] = servo_targets["BYTarget"]
    else:
        servo_targets["BaseY"] += step_size if dy > 0 else -step_size

    servos["BaseX"].write(int(servo_targets["BaseX"]))
    servos["BaseY"].write(int(servo_targets["BaseY"]))




while True:
    mode_state = not mode.value()
    enable_state = not enable.value()
    if mode_state == 1: # Enter calibration mode when switch is in hold position
        calibrate()
        time.sleep_ms(500)
    else:
        if enable_state == 0: # Auto mode
            latest_line = None
            while sys.stdin in select.select([sys.stdin], [], [], 0)[0]:
                latest_line = sys.stdin.readline()

            if latest_line:
                x_str, y_str = latest_line.strip().split(',')
                error_x = int(x_str)
                error_y = int(y_str)

                move_target("LR", error_x*-1)
                move_target("UD", error_y)

                if random.randint(0,60) < 1:
                    blink()
                    time.sleep_ms(60)
                    lid_sync()
            time.sleep_ms(0)
            lid_sync()
            if abs(servo_targets["UD"] - 90) >= deadzone_neck or abs(servo_targets["LR"] - 90) >= deadzone_neck:
                if not neck_flag:
                    neck_trigger_time = time.ticks_ms()
                    neck_flag = True
                if neck_flag and (time.ticks_ms() - neck_trigger_time) >= neck_timer_ms:
                    neck_target(servo_targets["LR"], servo_targets["UD"])
                    neck_flag = False
            neck_smooth_move()

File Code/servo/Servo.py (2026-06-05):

import RPi.GPIO as GPIO
import time
from adafruit_servokit import ServoKit
import threading


class Servo(threading.Thread):
    def __init__(self, servoName, kit=None):
        super().__init__()

        self.servoName = servoName
        self.kit = kit

        self.running = True

        self.OE_PIN = 17
        if GPIO.getmode() is None:
            GPIO.setmode(GPIO.BCM)
        GPIO.setup(self.OE_PIN, GPIO.OUT)
        GPIO.output(self.OE_PIN, GPIO.LOW)

        self.PIN_PINCE_DROITE = 3
        self.PIN_PINCE_GAUCHE = 7

        self.PINCE_OUVERTE = 10
        self.PINCE_FERMEE = 70

        self.kit.servo[self.PIN_PINCE_DROITE].angle = self.PINCE_OUVERTE
        self.kit.servo[self.PIN_PINCE_GAUCHE].angle = self.PINCE_OUVERTE
        time.sleep(0.3)

    # ---------------- THREAD MAIN ----------------
    def run(self):
        try:
            if self.servoName == "rightArm":
                self.arm_with_claw(arm_pin=0, claw_pin=self.PIN_PINCE_DROITE, direction=1)

            elif self.servoName == "leftArm":
                self.arm_with_claw(arm_pin=2, claw_pin=self.PIN_PINCE_GAUCHE, direction=-1)

            elif self.servoName == "head":
                self.look_around(pin=1)

        except Exception as e:
            print(f"[Servo ERROR] {e}")

        finally:
            self.stop_servos()
            GPIO.output(self.OE_PIN, GPIO.HIGH)

    # ---------------- ARM + CLAW SYNCHRO ----------------
    def set_claw(self, claw_pin, angle):
        self.kit.servo[claw_pin].angle = angle
        time.sleep(0.15)

    def open_claw(self, claw_pin):
        self.set_claw(claw_pin, self.PINCE_OUVERTE)

    def close_claw(self, claw_pin):
        self.set_claw(claw_pin, self.PINCE_FERMEE)

    def arm_with_claw(self, arm_pin, claw_pin, direction):
        speed = 0.5 * direction

        self.open_claw(claw_pin)

        time.sleep(0.2)

        # avance bras
        self.kit.continuous_servo[arm_pin].throttle = speed
        time.sleep(0.5)

        self.close_claw(claw_pin)
        time.sleep(0.3)

        # stop bras
        self.kit.continuous_servo[arm_pin].throttle = 0
        time.sleep(0.2)

        # retour bras
        self.kit.continuous_servo[arm_pin].throttle = -speed
        time.sleep(0.5)

        self.kit.continuous_servo[arm_pin].throttle = 0

        self.open_claw(claw_pin)

    # ---------------- HEAD ----------------
    def look_around(self, pin):
        self.kit.continuous_servo[pin].throttle = 0.2
        time.sleep(0.4)

        self.kit.continuous_servo[pin].throttle = -0.2
        time.sleep(0.4)

        self.kit.continuous_servo[pin].throttle = 0

    # ---------------- STOP ----------------
    def stop_servos(self):
        try:
            if self.kit:
                for i in range(16):
                    try:
                        self.kit.continuous_servo[i].throttle = 0
                    except:
                        pass
        except:
            pass

    def stop(self):
        self.running = False
        self.stop_servos()

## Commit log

2026-06-05 Add hat support file
    [support tete vf.SLDPRT]
2026-06-05 ajout des codes audios + main
2026-06-05 ajout servo
2026-06-05 Refactor error handling and comments in Main.py
    [Main.py]
